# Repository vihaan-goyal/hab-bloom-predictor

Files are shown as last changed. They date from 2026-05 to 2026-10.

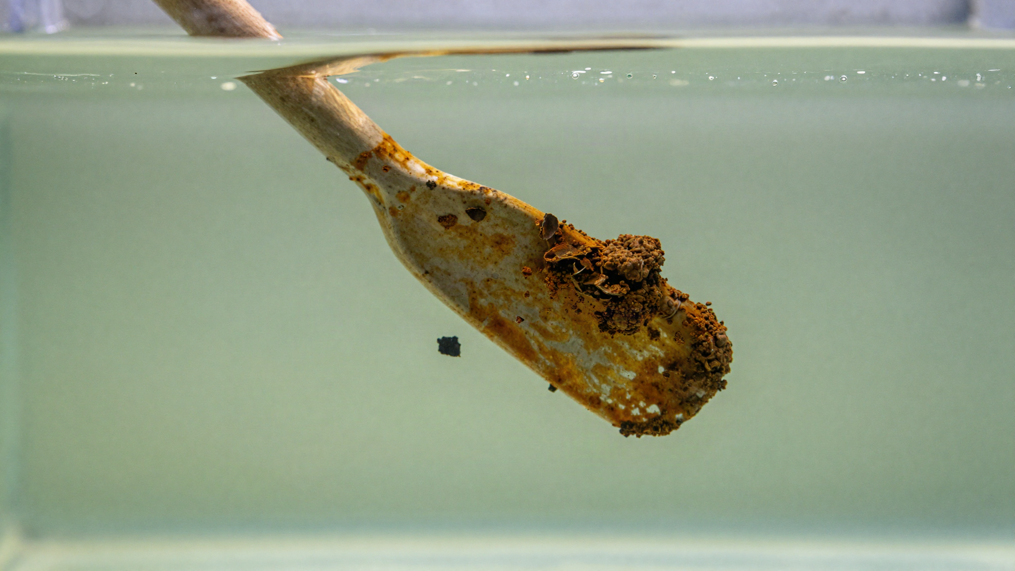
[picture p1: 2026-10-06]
figures/device_concept/shot1_flocs.png

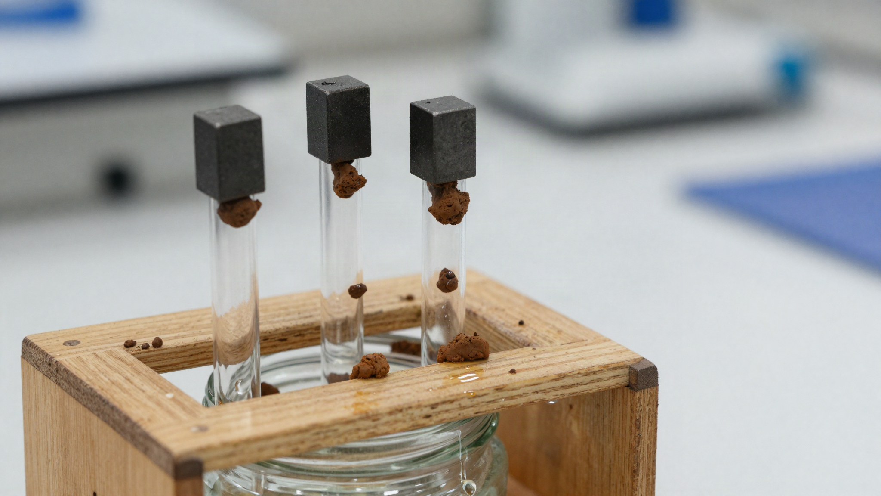
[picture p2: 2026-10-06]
figures/device_concept/shot3_release.png

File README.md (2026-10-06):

# HAB Bloom Predictor

**Predictability and its limits: a 21-day early warning system for chlorophyll exceedances in Long Island Sound**

Vihaan Goyal, Westhill High School, Stamford, Connecticut

---

**Label rebuilt (2026-09-23).** The Long Island Sound label used to come from DEEP's CTD fluorometer, which read 2.1-4.8x DEEP's own lab chlorophyll in 1994-1999, 1.8-3.2x in 2009-2013 and 0.8-1.05x from 2016 on. DEEP confirmed its lab and methods are unchanged for 30+ years, that the CTD switched from a SeaBird to a YSI EXO2 around 2009/2010, and recommended the lab data. The label and every chlorophyll feature were rebuilt on the lab scale (`Corrected_Chlorophyll`) under a pre-registration (S1, now the default), and all seven pre-registered predictions were right. Current numbers: `notes/S1_NUMBERS_SHEET.md`; rationale: `notes/LABEL_REBUILD_PREREG.md`.

## What this project shows

A regularized logistic regression forecasts chlorophyll-a exceedances (>10 ug/L within 21 days of a station visit) across Long Island Sound with useful ranking skill (pooled walk-forward AUC 0.693 after the 2026-09-28 audit; it beats a past-years calendar over 2016-2025, +0.077, p < 0.001, pre-registered, and ties it in 2023-25), but alert precision is capped near 0.12 regardless of model class, feature set, threshold, era, or spatial alerting policy. Thirteen pre-registered improvement attempts were rejected (sensor label; not re-run). The central finding is that this precision ceiling is mechanistic, not a modeling failure:

1. **Rarity.** Exceedances are rare in the test years (4.5% of station-days at the 21-day horizon), and rare events cap precision regardless of model. The low precision is mostly rarity, not only (the Sound also separates the classes less well, overlap 0.62 against 0.52 in Narragansett Bay). The old "2014 cliff" (sensor-label bloom share 0.42–0.59 in 2009–2013 → 0.03–0.11 from 2014) was mostly a CTD sensor scale change (SeaBird to YSI EXO2 around 2009/2010), confirmed by CT DEEP; the lab record has no 2014 step, but it does show a real, temporary low in 2012–2017. It is not a TMDL effect and not a DEEP lab change.
2. **Sampling.** The median gap between chlorophyll measurements is 21 days, equal to the forecast horizon. 48% of inter-sample gaps exceed the horizon, so many predicted events cannot even be verified.

Across eras and label definitions the system delivered a roughly constant 2.5 to 3.4x precision lift over the base rate on the sensor label (not re-run); after the 2026-09-28 audit the 21-day station-day lift is 1.63x at t* = 0.20. No intervention has moved that multiplier.

## The early warning system

**Leak fix (2026-09-28).** Four of the 35 features (`chl_climatology`, `chl_anomaly`, `tidal_gt_anom`,
`tidal_msl_anom`) were anomalies against climatologies averaged over the whole 1993-2025 record, so
test-period data leaked into training rows. They now use only data dated before each row
(`label_rebuild.py`, `add_tidal_features.py`; fix first found on the `worktree-climatology-fix`
branch, now archived as a tag). All numbers below are re-run on the leak-free features.

Operating point frozen by a pre-registered rule (highest threshold with out-of-sample 2020 to 2022 POD >= 0.8), evaluated once on out-of-sample 2023 to 2025 (walk-forward CV predictions, rebuilt label):

| Metric | Value | 95% CI (clustered bootstrap) |
|---|---|---|
| POD (recall) | 0.791 (34 of 43 events) | [0.636, 0.904] |
| FAR (1 - precision) | 0.885 | [0.835, 0.935] |
| Precision | 0.115 (~1.5x over 7.7% base rate) | [0.065, 0.165] |
| CSI | 0.122 (sensor label; not re-run) | [0.075, 0.169] |

Alert threshold t* = 0.20, from the pre-registered rule (highest threshold with out-of-sample 2020-22 POD >= 0.8), now the single constant `locked_pipeline.T_STAR_21` used by deploy and every analysis (decided 2026-09-28). On the original sensor label the table read POD 0.875, precision 0.125 over a 4.6% base rate, and selection-to-test transfer was near exact (POD 0.864 -> 0.875). At the 21 recurring-bloom stations (defined on pre-test data), detection is 91% at precision 0.137 (sensor label; not re-run). A station-gated alert policy was tested and rejected: false alarms arise at bloom-prone stations during non-bloom periods, so the ceiling is temporal, not spatial (sensor label; not re-run). A sustained-exceedance secondary label raises the lift to 3.4x but leaves precision near 0.10 (sensor label; not re-run).

The framing rationale: a missed bloom carries ecological and shellfish-industry costs, while a false alarm prompts a water sample at a station where, half the time, no sample would otherwise occur in the window.

## Locked pipeline

- Model: LogisticRegression, C=0.05, L2, balanced class weights, 35 features
- Label: any chlorophyll-a exceedance >10 ug/L within 21 days of a station visit
- Evaluation: rolling-origin cross-validation (train <= T-2, test = T), folds 2015 to 2025, station-year clustered bootstrap for all interval claims
- Canonical data file: `data/hab_features_tidal_S1.csv` (default; lab-consistent label), plus in-script merges of percent saturation and gust features. `HAB_FEATURES_CSV=data/hab_features_tidal.csv` reproduces the original sensor label.
- Dominant signal: chlorophyll history (~42% grouped feature importance; sensor label; not re-run)

Complexity does not help (sensor label; not re-run): XGBoost cost 33 points of precision against this baseline. Nutrient forward-fill, ERA5 wind, Kd490, neighbor bloom probability, station-month rates, and chlorophyll acceleration were all tested and rejected.

## Key ecological context

- The sharp 2014 step in the old sensor label was mostly a CTD sensor scale change (SeaBird to YSI EXO2 around 2009/2010), confirmed by CT DEEP on 2026-09-22/23; it is not a TMDL effect and not a DEEP lab change. The lab record has no 2014 step, but it does have a real, temporary low in 2012-2017 (lab exceedance share 0.03-0.07, against 0.10-0.23 before and 0.10-0.19 after)
- Biomass-bloom decoupling at western stations (A4, B3) after 2014, with near-zero NOx observations (sensor label; not re-run)
- Bloom frequency peaks February to March at 0 to 5 C, driven by cold-water diatoms, not summer cyanobacteria (sensor label; not re-run)
- Chlorophyll biomass (this project's target) skews west and tracks eutrophication; toxin-producing HAB species monitored by the state concentrate in eastern LIS. This system is a eutrophication early warning tool, not a direct toxin predictor.

## Repository structure

```
src/
  models/
    rolling_origin_cv.py            evaluation harness (canonical instrument)
    final_evaluation_threshold_sweep.py   single-split evaluation
    threshold_robustness.py         label-definition robustness (10 vs 12 ug/L)
    experiments/                    rejected improvement attempts (13)
  deploy/                           daily inference on the locked model;
                                    dashboard.html is stale (see DASHBOARD.md)
data/                               gitignored; see Data sources
figures/
paper/                              LaTeX (Overleaf)
```

Warning-system scripts (`scripts/warning/`): `scripts/warning/warning_operating_point.py` (threshold selection), `scripts/warning/warning_robustness.py` (CIs, extra years, per-station), `scripts/warning/warning_station_gate.py` (rejected gate experiment), `scripts/warning/grouped_station_report.py`.

## Data sources

| Source | Content | Access |
|---|---|---|
| CT DEEP / LISICOS via UConn ERDDAP | In-situ water quality, 1993 to 2025, ~monthly per station | public, merlin.dms.uconn.edu:8080 |
| UConn ERDDAP DEEP_Nutrient | Nutrient observations (NOx, DIP) | public |
| USGS stream gauges | Connecticut, Thames, Housatonic discharge | public |

The `data/` folder is not in git. Reproduce it from the public sources above; the raw water quality export is a single ERDDAP CSV query.

## Reproducing the headline numbers

```
conda activate base
python src/models/rolling_origin_cv.py --horizon 21      # pooled AUC 0.693 (S1, after the audit)
python scripts/warning/warning_operating_point.py --target-pod 0.8 --test-from-cv
python scripts/warning/warning_robustness.py --t-star 0.20
```

These use the S1 default input, `data/hab_features_tidal_S1.csv` (built by `python src/models/label_rebuild.py build`). Prefix with `HAB_FEATURES_CSV=data/hab_features_tidal.csv` to reproduce the original sensor label (pooled AUC 0.852 there).

## Status notes

- Horizon is standardized at 21 days throughout. An earlier single-split evaluation used a 28-day label; where its numbers appear in older notes they are superseded.
- `src/deploy/daily_inference.py` runs the locked pipeline (v2): it imports `locked_pipeline`, fits the LR walk-forward in-process, and loads no serialized model. The residual stale artifact is `src/deploy/dashboard.html`, whose sidebar still reads "Model: XGBoost / AUC 0.827" and which parses `aeration_score`/`do`/`temp`/`intervene` columns the current script no longer emits.
- Aeration intervention results are pending a rerun on corrected data and should not be quoted yet.

---

## Findings

Five results, each with the number that supports it. The negatives are the substance,
not the leftovers.

### 1. The alert beats "always alert", and nothing else

Until August 2026 this repo contained no trivial reference forecast, so "POD 0.875"
(the original sensor-label figure) had nothing to be measured against. `src/models/reference_baselines.py` adds four
(always-alert, station x month climatology, station x day-of-year climatology,
persistence) with a paired station-year clustered bootstrap of the lift difference.

| Level | base rate | model lift | clearly beats |
|---|---|---|---|
| Station-day (test, t*=0.20) | 0.077 | **1.63x** | always-alert only, +0.63 [+0.35, +0.92] |
| Basin-day (n=41, 9 events) | 9 of 41 | 1.75x | nothing; +0.76 [-1.00, +2.25] vs always-alert |

(Rebuilt, leak-free label, t*=0.35; before the 2026-09-28 leak fix 2.59x and basin 2.14x; was 2.63x on 956 rows / 48 events, and basin 1.37x on 12 events, on
the original sensor label.)

At station-day level the model is clearly better than no information. Persistence
scores a higher lift (3.26x) at a much lower POD (0.279 against the model's 0.791).
Climatology was not tested fairly on the rebuilt label (its validation-chosen threshold
degenerated to t=0, i.e. always-alert), so the original statement stands: not clearly
better than climatology. At basin level neither the model (1.75x) nor persistence clearly beats always-alert.

**Mechanism:** basin aggregation raises the base rate from 0.045 to 9 of 41 basin-days,
and lift = precision / base_rate. The aggregation that buys verification coverage spends
the model's clear advantage over always-alert. Report the station-day product, not the
basin one.

### 2. Searching 912 operating points finds noise

`src/models/basin_search.py` pre-registers a 912-cell grid (threshold x west-lon cut x
season gate x min-stations x aggregator), selects on validation only by a fixed rule,
and scores one configuration on test once. A permutation null re-runs the entire
search on shuffled labels.

- best real validation lift: **2.05x** (was 1.84x on the original sensor label)
- permutation null best-lift (200 shuffles): median **1.79x**, 95th percentile 2.86x
- the real result sits at the **70.5th percentile of noise**: inside the null

With this few validation events, any search over this space returns ~1.8-2x whether or
not the labels carry information. The selected configuration scores lift 1.56x on test;
that number is the output of selecting on noise and is not reported as an improvement. This is a direct quantitative demonstration of the failure
mode recorded in `notes/PRECISION_CEILING_INVESTIGATION.md` Finding 1.

### 3. The detector cannot see the HAB it is named for

`notes/BENCHMARKS.md` and Hattenrath-Lehmann & Gobler (2016) record that CTDEEP -- the
provider of this dataset -- reported *Cochlodinium* (rust tide) patches in Long Island
Sound in 2012 and 2016, plus an extensive bloom in Port Jefferson Harbor in 2016.

On the sensor label (not re-run), our Jul-Oct chlorophyll for 2016 is **0.6 sd below** the multi-year average (mean 4.21
vs 2012's 11.18), and across all 11,447 station-days exactly **one** reading reaches
the 100 ug/L rust-tide dense-patch level. Rust tide forms localised surface
aggregations that a station-day mean over multiple casts dilutes away.

Consequence for framing: chl-a > 10 ug/L is a **biomass** threshold, not a harm
threshold. Benign winter diatom blooms are counted; genuine HABs are missed. What this
model predicts is phytoplankton biomass exceedance. See `notes/LITERATURE_NOTES.md`.

### 4. Temperature is nearly uninformative here

Bloom rate below 15 C is **22.4%** versus **25.5%** at or above it (n=2,787
exceedances with paired temperature; sensor label; not re-run). A third of exceedances fall below the 15 C
threshold Reinl et al. (2023) use to define a cold-water bloom, and 20% below 5 C.
This cuts against the warming-drives-blooms framing that dominates the HAB
literature, and is consistent with the Feb-Mar cold-water diatom peak.

### 5. No point of no return exists

`src/models/point_of_no_return.py` tests, over 544 pre-onset observations (153 events),
whether a bloom ever becomes unavoidable. Two independent methods share **zero** rows. The
model-free test (50 matched historical analogues per state) peaks at **0.42**, median
0.02 (was 0.62 / 0.04 on the original sensor label). The model counterfactual's apparent
answer -- 42% of summer events locked in -- collapses to **0%** once temperature, salinity and tides are allowed
to move within their own observed station-season range, so it measures lever
restriction rather than inevitability.

### The rejected-attempts ledger, enumerated

This README previously said "thirteen pre-registered improvement attempts were
rejected" but named only seven and quantified one. The full ledger, with deltas where
they were logged (sources: `notes/PRECISION_OPTIMIZATION_LOG.md`,
`notes/PRECISION_PUSH_TRACKER.md`, `src/models/experiments/`):

| # | Attempt | Outcome |
|---|---|---|
| 1 | Nutrient forward-fill | **-10.4pp** precision (stale monthly samples) |
| 2 | NOAA ASOS wind (land-based) | **-4pp** |
| 3 | MODIS satellite CHL | **-7.8pp** (4 km too coarse) |
| 4 | ERA5 wind stress | **-6.3pp** (corr -0.003; wind is noise for LIS blooms) |
| 5 | Kd490 water clarity | **-2.2pp** (78.8% null in the merge) |
| 6 | UConn nutrients | **-4.9pp** (still monthly cadence) |
| 7 | River discharge lags | no signal, corr < 0.03 at every lag; screened out |
| 8 | Isotonic/Platt calibration | breaks the probability scale; val too small (~67 positives) |
| 9 | XGBoost | **-33pp** precision |
| 10 | Station-month bloom rate | rejected; delta not logged (`experiments/test_station_month_rate.py`) |
| 11 | Chlorophyll acceleration | rejected; delta not logged (`experiments/test_chl_acceleration.py`) |
| 12 | Neighbor bloom probability | rejected; delta not logged (`experiments/test_neighbor_bloom_prob.py`) |
| 13 | Station-gated alert policy | rejected; false alarms arise at bloom-prone stations in non-bloom periods, so the ceiling is temporal, not spatial |

Rejected since, under rolling-origin CV and this session's baselines (sensor label; not
re-run, except the basin search, re-run on the rebuilt label): selective
prediction / station abstention (CI [-0.024, +0.037] straddles zero); stratification
features (paired AUC -0.014 [-0.021, -0.007] — real physics, no marginal signal);
label refinement (raises raw precision 0.175 to 0.380 while lift *falls* 5.72 to 2.91 —
a base-rate illusion); the ensemble (+0.0038 AUC vs LR, CI [-0.0100, +0.0201]); and the
912-configuration basin operating-point search (70.5th percentile of its own permutation
null, i.e. inside it). The consistency of these failures across mechanism, model class, and alerting
policy is the precision-ceiling finding.

### Also worth knowing

- **Model class does not matter** (sensor label; not re-run). Ensemble vs locked LR on the same test split:
  +0.0038 AUC, 95% CI [-0.0100, +0.0201]. Every tree ensemble in
  `data/full_model_comparison_results.csv` scores clearly worse (VotingEnsemble 0.7918,
  StackedLR 0.7697) than LR (0.8139-0.8157).
- **A typical bloom onset carries one in-situ reading in the preceding month**
  (median 3 in 90 days; median inter-visit gap 21 days = the forecast horizon).
- **There is no spare data.** The raw ERDDAP export holds 106 real stations and 11,508
  station-days with usable chlorophyll; the model already uses 11,447 (~99.5%).

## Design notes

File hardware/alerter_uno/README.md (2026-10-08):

# Alerter on an Arduino Uno: build guide

The alerter is the loop's brain for one tank:
- each day it gets the forecast `p` and the tank's chlorophyll;
- it decides ON/OFF with the same rules as `src/sim/loop_controller.py`;
- it switches a relay (the treatment) and shows the state on LEDs and a buzzer.

The Uno has no Wi-Fi, so the laptop sends the daily values over USB. An ESP32 is only needed
later, if the box must run without a laptop.

**What gets measured, and how:**

| Measurement | Why | How | Auto / by hand | Stage |
|---|---|---|---|---|
| Chlorophyll | model input (required), OFF rule | DIY fluorometer | auto | 5 |
| Temperature | model input, safety | DS18B20 probe | auto | 3 |
| pH | safety (bubbling and percarbonate shift it) | analog pH probe | auto | 4 |
| Dissolved oxygen | model input (optional), safety < 4 mg/L | aquarium DO kit | by hand, daily | 6 |
| Salinity | model input (optional) | refractometer | by hand, every 2-3 days | 6 |
| Cell counts | the real endpoint; checks the fluorometer | microscope + Sedgewick-Rafter slide | by hand, every 1-2 days | 6 |
| Ammonia / nitrate / phosphate / H₂O₂ | method safety limits | test strips/kits | by hand, at each re-measure | 6 |
| Non-target survival | arm D harm check | *Artemia* 24-h survival | by hand | 6 |

**Build one stage at a time. Don't start the next stage until the current one passes its "done when" check.**
Dates fit `EXECUTION_PLAN.md`: build and calibrate by Oct 24, cultures Oct 15-31, warm-up Nov 10.

| Stage | What | Target | New cost |
|---|---|---|---|
| 0 | Parts check | Sep 27 | $0 |
| 1 | Logic + lights | Sep 27-28 | $0 (kit) |
| 2 | Relay + pump | by Oct 4 | ~$25 |
| 3 | Temperature | by Oct 4 | ~$8 |
| 4 | pH probe | Oct 5-11 | ~$30 |
| 5 | Fluorometer (chlorophyll) | Oct 5-18 | ~$20 |
| 6 | Hand-measurement kit | Oct 12-24 | ~$90 + borrowed microscope |
| 7 | Laptop link + logging | Oct 19-24 | $0 |
| 8 | Dry run on a real tank | Oct 26 - Nov 9 | $0 |
| 9 | Dosing module (inline dilution, peroxide) | Oct 12-24 | ~$70 |

**Progress:** stages 1 and 2 passed on 2026-09-26: Test A, lights, buzzer, and the bare relay
clicking on D10 (LED as the pretend pump; the real pump isn't bought yet).
On 2026-09-30 the new Uno (COM5) passed Tests A, B and C by hand, every line matching, and the bare
relay clicked on D10 with `hardware/relay_click_test/relay_click_test.ino` (toggles D10 every second).
On 2026-10-05 the Adafruit TSL2591 (STEMMA QT cable, no soldering) read on the new Uno with `USE_TSL2591 1`;
the pH board reads (zero point ~3.6 V in tap water, buffers not yet bought, so not calibrated).
On 2026-10-07 the DS18B20 probe (red/yellow/blue leads taped to jumpers, 4.7 kΩ pull-up, 12-bit) read
correctly on D3 (user report: stage 3 passed).

## Shopping list (what to order now)

Already on hand: Uno, breadboard, M-M wires, blue/green/white LEDs, 220/330/10k Ω resistors,
PN2222A transistors, passive buzzer, bare 5 V relay, 1N4007 diode.

| # | Item | For | Approx. |
|---|---|---|---|
| 1 | Male-to-female jumper wires ([ELEGOO 120-pc M-F/M-M/F-F](https://www.amazon.com/dp/B01EV70C78)) | relay pins, sensor boards | $6 |
| 2 | 12 V diaphragm air pump ([search: 12 V diaphragm air pump](https://www.amazon.com/s?k=12v+dc+diaphragm+air+pump+aquarium); the listing found first is gone) + 12 V 2 A adapter with barrel-jack screw terminals ([bundle](https://www.amazon.com/dp/B08GX5Z4MR)) + air tubing and an air stone | stage 2 (the real pump) | $20 |
| 3 | DS18B20 **waterproof** probe ([5-pack with 4.7 kΩ resistors](https://www.amazon.com/dp/B0C8J77NJR)) | stage 3 | $10 |
| 4 | pH module + BNC probe ([PH-4502C type](https://www.amazon.com/dp/B07KDPQGYD)) + buffer powders 4.00/6.86/9.18 ([VIVOSUN 18-pack](https://www.amazon.com/dp/B0D4L8Y7BT)) | stage 4 | $35 |
| 5 | [Adafruit TSL2591](https://www.amazon.com/dp/B00XW2OFWW) + [LEE 106 Primary Red gel](https://www.amazon.com/dp/B003DIGLV8) + cuvettes with **4 clear sides** ([Globe 4.5 mL, 100](https://www.amazon.com/dp/B08N5B5PL8)) + [470 nm blue LEDs](https://www.amazon.com/dp/B091SLR9SB) | stage 5 | $40 |
| | **Total** | | **~$110** |

Links found 2026-09-26; check the price, the rating and that it still matches before buying. The
cuvettes must have 4 clear sides, because the sensor looks in at 90° to the LED. Calibrate the pH probe
with the 6.86 and 9.18 buffers (they bracket seawater's ~8).

Stage 6 (hand kits: DO kit, refractometer, counting slide, test strips, ~$90) can wait until mid-October;
it's listed in stage 6 below and in `notes/mitigation/MATERIALS_LIST.md`.

---

## Stage 0: parts check

Go through the kit against the stage 1 list. Write down what's missing, and order stages 2-5 parts together (one shipping wait).

**Done when:** you have everything for stage 1 on the desk, and the stage 2-5 order is placed.

## Stage 1: logic + lights (kit parts only, ~1 hour)

**Parts** (on hand): Uno, breadboard, green, blue and white LEDs, 220/330 Ω resistors, passive buzzer, NPN transistor + 330 Ω–1 kΩ, M-M jumper wires.

**Visual wiring: [circuito.io design](https://www.circuito.io/app?components=512,9591,9594,11021,11050,11372,956215)**
(snapshot `wiring_circuito.jpg`). Build it exactly as shown, with two colour swaps:
- circuito's **yellow** LED = your **white** LED (warning);
- no relay in the picture: D10 stays empty until the relay goes there in stage 2; the blue LED already shows when the relay would be ON.

The sketch uses circuito's pins:

| Uno pin | Goes to |
|---|---|
| D6 | green LED → 330 Ω → GND: **idle** |
| D5 | blue LED → 100 Ω (220 Ω also fine) → GND: **treatment ON** |
| D9 | white LED (circuito's yellow) → 220 Ω → GND: **warning** |
| D10 | empty in stage 1; stage 2: the relay transistor |
| D2 | 330 Ω → NPN transistor base; buzzer between 5V and the collector; emitter → GND |
| D3 | DS18B20 yellow wire, 4.7 kΩ to 5V (stage 3) |
| 5V / GND | breadboard rails |

`schematic.png` (drawn by `draw_schematic.py`) is the same circuit as a circuit diagram, plus the
bare-relay driver that circuito can't draw.

The sketch drives a **passive** buzzer (it plays a 2 kHz tone). Change `BUZZ_HZ` for a different pitch.

⚠ **Full-size breadboards split their power rails in the middle** (look for a gap in the red/blue
lines). Jumper the top + to the bottom + and the top − to the bottom −, or parts in the bottom half
get no power. This silenced the buzzer on 2026-09-27: it was in the bottom half, powered from a dead rail.
A buzzer wired straight from D2 to GND also works, just more quietly.

**Flash it:**
1. Open `alerter_uno.ino` in the Arduino IDE.
2. Select Board → Arduino Uno and the COM port, then click Upload.
3. Open the Serial Monitor at **115200** baud with **"Newline"**.

**Test A**: paste one line at a time (X = 3, C_ok = 5):

```
1 0.2 3      -> idle            (green)
2 0.6 4      -> START           (3 beeps, blue, next_check=5)
3 0.7 6      -> ON
4 0.7 8      -> ON
5 0.5 9      -> ON next_check=8 (p not below T_off 0.40: keep going)
8 0.3 4      -> OFF             (1 long beep, green)
9 0.3 3      -> idle
```

**Test B (MAX_ON = 12 days)**: send `reset`, then `1 0.6 4`, then days 2-14 as `<day> 0.9 20`.
- Day 13 prints `STOP_MAX_ON`.
- Day 14 restarts (episodes=2), because `p` is still high.

The Python controller gives the same states on both tests (checked 2026-09-26).

**Test C (handover + floor, added 2026-09-28)**: send `reset`, `x 3`, `cok 3`, `mode H`, `warm 2`,
`floor 0.8`, then one line at a time:

```
1 0.1 2.0    -> idle
2 0.1 2.2    -> idle
3 0.1 4.6    -> idle            (rule fires: rose 2 days and > 2 x warm; forecast still low)
4 0.2 5.1    -> idle
5 0.2 6.0    -> START           (handover: rule fired 2 days ago, forecast never did)
6 0.3 6.5    -> ON
8 0.3 7.0    -> ON              (day 7 skipped: fine)
9 0.3 1.5    -> ON              (1st reading below the floor 0.8 x 2 = 1.6)
10 0.3 1.4   -> OFF_FLOOR       (2nd in a row: H4 floor OFF)
11 0.3 1.3   -> idle
12 0.6 5.0   -> START           (forecast)
```

`alerter_link.py --replay <file> --sim --mode H --warm 2 --floor 0.8 --x 3 --cok 3` prints the same
states (Python reference, 2026-09-28). Run it on the board too: 0 mismatches is the pass mark.

**Other commands:**
- `status`
- `x 2`, `cok 4.5`
- `mode F` (forecast only), `mode R` + `warm 1.8` (rule trigger: chl rose on 2 calendar days AND
  > 2 × warm-up mean), `mode H` + `warm 1.8` (forecast, with the 2-day handover to the rule: arm B)
- `floor 0.8` (H4: 2 readings in a row below 0.8 × warm while ON → `OFF_FLOOR`; `floor 0` for the
  false-alarm arm D), `maxon 3` (MAX_ON in **days since START**; 0 = 4 × X; peroxide 3 with `x 1`)
- `pulse <s>` (added 2026-10-02, peroxide dosing pump): while ON, the relay runs for `<s>` seconds at
  START and at each check day that continues the episode, then switches off; the state still prints
  `ON`, and the day line ends with `pulse=<s>s`. `pulse 0` (default) holds the relay for the whole
  episode (air pump), so Tests A-C are unchanged.
- `skip`: the next pulse is skipped (the day line shows `pulse=skipped`); send it when the low-range
  kit reads an H₂O₂ residual above 0.5 mg/L.
- **Peroxide setup:** `x 1`, `maxon 3`, `pulse <s>`, where `<s>` = seconds the calibrated pump needs to
  deliver the pulse volume (0.265 mL of 3% per 10 L for 0.8 mg/L; from the weigh-calibration in
  mL/s). Because MAX_ON counts days since START, this gives at most 3 pulses (START day and the next
  two check days) and `STOP_MAX_ON` on day 4. The 2.8 mg/L residual stop and the pH > 9.0 stop are
  **not** automatic in the firmware: send `stop` by hand, or use `alerter_link.py --stop "..."` /
  `--ph-max 9.0`.
- `temp 10 17` (temperature warning window; default 10-17 °C for the planned 12-15 °C run)
- `stop` for a safety stop, e.g. when the DO kit reads < 4 mg/L. With the laptop link, use
  `--today ... --stop "DO 3.6 mg/L"` instead, so the stop is logged and replayed after a reset.

**Done when:** Tests A, B and C print exactly the lines above, and the LEDs and buzzer match.

## Stage 2: relay + pump (~$25)

**Parts:**
- 1- or 2-channel 5 V opto-isolated relay module;
- a 12 V aquarium air pump (or peristaltic pump) + 12 V adapter;
- a DC barrel jack or screw-terminal adapter.

**Wiring:**
- Relay VCC→5V, GND→GND, IN→D10.
- The pump's 12 V + wire goes through the relay's **COM → NO** contacts; the − wire goes straight back to the adapter.
- The Uno and the 12 V pump do **not** share power.
- Most relay modules are **active-low**: with a module, set `RELAY_ACTIVE_LOW = true`. If the relay clicks ON while the sketch says idle, flip it.

**Bare 5-pin relay instead of a module** (the kit's blue SRD-05VDC-SL-C). Breadboard picture:
`relay_breadboard.png` (drawn by `draw_relay_breadboard.py`, since circuito.io can't draw this part).
- The coil needs ~70-90 mA, more than an Uno pin can give, so drive it with the NPN transistor:
  - D10 → 330 Ω (or 1 kΩ) → transistor **base**;
  - **emitter** → GND;
  - **collector** → one coil pin; the other coil pin → 5V.
- Put a **1N4007 diode across the coil**, with the striped end (cathode) on the 5V side. It absorbs the voltage spike when the coil turns off; without it the transistor or Uno can die.
- Pins: the top of the relay shows the pinout. With the relay off, **COM** is connected to **NC** (a multimeter beeps). The pump goes on **COM → NO**.
- `RELAY_ACTIVE_LOW = false` (the sketch default): a HIGH on D10 turns the transistor, and so the relay, on.
- The legs sit across the breadboard's centre gap. If they don't fit, solder short wires on.

⚠ **Never put 120 V mains on the breadboard or a bare relay.** A mains-powered pump goes on a
**smart plug** or an enclosed relay box ("IoT Power Relay") on a **GFCI** outlet, with the
sponsor's OK.

**Done when:** rerunning Test A makes the pump run from day 2 to day 8, and stop otherwise.

## Stage 3: temperature (~$8)

**Parts:** DS18B20 **waterproof** probe, 4.7 kΩ resistor (or two 10 kΩ in parallel).

**Wiring:**
- red→5V, black→GND, yellow→D3;
- the resistor goes between D3 and 5V.

**Code:**
- Arduino IDE → Library Manager → install `OneWire` and `DallasTemperature`.
- Set `USE_DS18B20 1` at the top of `alerter_uno.ino` (the code is already written and compile-checked).
- It reads every 10 s and alarms outside the window (default 10-17 °C, set with `temp <lo> <hi>`;
  white LED, fast beeps). `read` prints all sensors; `status` shows the temperature.

**Done when:**
- the probe agrees with a kitchen thermometer within 0.5 °C in a glass of water;
- ice water triggers the alarm, and room-temperature water clears it.

## Stage 4: pH probe (~$30)

**Parts:**
- analog pH probe kit with a BNC probe and the blue PH-4502C board (or DFRobot Gravity pH);
- pH 4.00, 6.86 and 9.18 buffer powder packets (calibrate with 6.86 and 9.18);
- distilled water for rinsing.

**Wiring:** board V+→5V, G→GND, Po→**A2** (A4/A5 are the TSL2591's SDA/SCL). Needs a working analog
header: the old Uno's broke off, so use the new board or a re-soldered header.

**Code** (written, compile-checked): set `USE_PH 1`. Then:
1. Probe in **pH 6.86** buffer, wait 1 min, type `cal686`.
2. Rinse, probe in **pH 9.18** buffer, wait 1 min, type `cal918`.
3. `read` now shows `ph=` (and the raw `ph_v=` volts). Calibration is stored in the Uno's EEPROM and
   survives unplugging; `cal` shows it, `calclear` erases it.
- `alerter_link.py --today` sends a **safety stop** if pH is outside 7.6-8.6 (change with
  `--ph-min/--ph-max`; peroxide runs use `--ph-max 9.0`). A safety stop ends a running treatment; it
  doesn't block a new start that day (same as the Python controller's `force_off`).

**Tips:**
- Store the probe tip wet (its cap with storage solution), never dry.
- The probe can read noisily when the air pump shares the water. Compare readings with the pump on and off.

**Done when:**
- the 6.86 and 9.18 buffers read within ±0.1 after calibration;
- seawater reads ~7.9-8.3 and agrees with a test strip.

## Stage 5: the fluorometer, chlorophyll (~$20, the hard part)

A blue LED makes chlorophyll glow red. A light sensor behind a red filter measures that glow.

**Autonomous accuracy (added 2026-10-02; the device must keep itself honest between service visits).**
Only the first item is built. The reference target, wiper, drift alarm and automatic rescaling are
**planned, not yet built**; the target and wiper need the servo (D11, `USE_SERVO`), which is
otherwise unused since 2026-10-01.
- **Dark reading every measurement:** LED off, LED on, subtract. Already in the code.
- **Reference target (planned):** once a day the servo swings a small piece of fluorescent plastic (or a sealed
  dye vial) in front of the sensor. Its reading should never change, so the device rescales `chlk`
  automatically when the LED or sensor drifts.
- **Wiper (planned):** the servo sweeps a soft rubber blade across the window before each reading, as RIDEM's
  sondes do.
- **Drift alarm (planned):** the device tracks its clear-water floor (lowest readings). If the floor rises for 3 or
  more days, it flags "needs cleaning".
- **Initial calibration** (blank + multiplier) is done once at setup against a reference: lab chlorophyll,
  cell counts, or a sonde. Service visits re-check it with 1-2 reference samples.
- **Side-by-side with a sonde (the main validation; plan §12 in `notes/mitigation/EXECUTION_PLAN.md`):**
  - deploy within about 1 m of a RIDEM or Narragansett Bay NERR sonde for 2-4 weeks;
  - fit `blank` and `chlk` as one linear fit of device counts against sonde µg/L (the same kind of
    correction DEEP applies to its own CTD);
  - report r, bias and drift. The target is ±20% of the sonde.

**Parts:**
- TSL2591 light-sensor breakout (Adafruit, works on 5 V);
- 470 nm blue LEDs + 220 Ω;
- red gel filter sheet (Roscolux/Lee "primary red", or a red theatre gel sample pack);
- square plastic cuvettes (4.5 mL);
- a small black box (3D print, or black foam board and tape).

**Layout:** the LED shines into the cuvette from one side. The sensor, behind the red filter, looks
in from 90° so it sees the glow, not the LED. Keep everything light-tight.

**Wiring:** TSL2591 VIN→5V, GND→GND, SDA→**SDA**, SCL→**SCL** (the two pins beside AREF, above D13;
same signals as A4/A5); blue LED on **D7** → 220 Ω → GND. STEMMA QT cable: red 5V, black GND,
blue SDA, yellow SCL.

**Code** (written, compile-checked): Library Manager → install **Adafruit TSL2591 Library** and
**Adafruit Unified Sensor**; set `USE_TSL2591 1`.
- `read` turns the blue LED off and on, takes 3 readings each (200 ms), and prints the difference as
  `fl=`, so room light cancels out. Too bright ("SATURATED") → `gain l`; too faint → `gain h` or `gain x`.
  The gain is saved with the calibration (EEPROM); changing it tells you to redo `blank` and `chlk`,
  because both are only valid at the gain they were measured at.
- **Zero:** cuvette of plain seawater in the box → `blank`.
- **Scale:** `chlk` is **µg/L of chlorophyll per signal count**. After the dilution series (below), fit
  reference chlorophyll in µg/L (acetone extraction, or a borrowed calibrated fluorometer) against
  `fl`, and type `chlk <slope>`. C_ok and the floor are then in µg/L. (If no µg/L reference exists,
  fit cells/mL instead and give C_ok and `warm` in cells/mL too; never mix the two units.)
  Then `read` prints `chl=` in µg/L, and `alerter_link.py --today --p 0.6` uses it automatically
  (leave out `--chl`).

**Calibration** (once cultures arrive):
1. Make a dilution series of the culture (100%, 50%, 25%, 12.5%, 6%, 0% in seawater).
2. Read each one 3 times.
3. Cell-count each one.
4. Fit reading vs cells (and µg/L if extracted chlorophyll is possible).

**Done when:**
- the blank (seawater only) reading is stable within ±5% over 10 minutes;
- the dilution series is a straight line (R² > 0.95).

## Stage 6: hand-measurement kit (~$90 + borrowed microscope)

| Item | Approx. |
|---|---|
| Aquarium DO test kit (saltwater) | $15 |
| Salinity refractometer (ATC) | $20 |
| Sedgewick-Rafter counting slide + transfer pipettes | $25 |
| Ammonia kit, nitrate/phosphate strips, H₂O₂ strips | $30 |
| Microscope (borrow from school) | $0 |

**Practice** on a culture flask for 3 days before any experiment. Do each measurement the way
you will in the real run, and fill in `src/lab/lab_data_template.csv`.

**Done when:**
- 3 days of practice data in the template;
- two counts of the same sample agree within 20%.

## Stage 7: laptop link + logging

**Script: `alerter_link.py`** (written 2026-09-27; needs `pip install pyserial`; close the Arduino IDE
Serial Monitor first, since only one program can use the port).

```
python hardware/alerter_uno/alerter_link.py --ports                  # find the Uno's COM port
python hardware/alerter_uno/alerter_link.py --demo                   # Test A, automatically
python hardware/alerter_uno/alerter_link.py --replay narragansett:F7 --days 400   # real history
python hardware/alerter_uno/alerter_link.py --today --p 0.62 --chl 7.4 --start 2026-11-10
```

- Every Uno reply is checked against the Python controller; any `MISMATCH` is printed and logged.
- Log: `hardware/alerter_uno/logs/alerter_log.csv` (not committed).
- **Uno resets:** opening the USB port restarts an Uno and wipes its ON/OFF state. `--today` replays the
  earlier days from the log with the buzzer muted (`mute 1`), then sends today's line.
- Add `--sim` to any command to try it with no board (a stand-in Uno built from the Python controller).
- **Checked on the real Uno (2026-09-27):** `--demo` (lights, beeps and relay clicks right), and all 3,287 days of
  Narragansett station F7 in 50 s: 115 ON days, 10 episodes (6 ended at MAX_ON, as expected on untreated
  water), **0 mismatches** with the Python controller, including days with missing `p` or chlorophyll.
- Later: read chlorophyll, temperature and pH from the Uno's sensors, and get `p` from the model automatically.

- **Loop settings (2026-09-28):** `--mode H` (default; arm B), `--warm <mean>`, `--floor 0.8` (0 for arm D),
  `--maxon 0|3`, `--temp-lo 10 --temp-hi 17`, `--stop "reason"` (logged manual safety stop). Values
  are sent with 6 significant figures and the Python reference uses the sent value, so a reading right
  at a threshold cannot disagree.

**Done when:** a 48-hour test logs with no gaps, and unplugging the USB and reconnecting it recovers cleanly.

## Stage 8: dry run on a real tank (Oct 26 - Nov 9)

Run one tank of plain seawater + culture at low nutrients for 2 weeks, exactly as the warm-up
will run:
- sensors logging;
- daily hand measurements;
- the loop active on the rule trigger (`--mode R --warm <warm-up mean>`).

**Done when:**
- 14 days with no missing daily rows;
- the fluorometer tracks the cell counts;
- nothing overheats, leaks or drifts.

Then the real 21-day warm-up starts on Nov 10.

## Stage 9: dosing module, inline dilution (added 2026-10-03; ~$70)

The peroxide is never squirted straight into the water. A circulation pump draws water in, the dosing
pump meters peroxide into that stream, a mixing hose blends it, and the mix leaves beside the air
stone. In the field the reservoir holds **7% H₂O₂**; on the bench it holds the **0.1% working
dilution** (`PROCEDURES.md` P6), because 0.8 mg/L in 10 L is only 0.11 mL of 7%, too little to meter.

```
water → intake (2-5 mm screen) → circulation pump (12 V) → mixing tee → 1 m mixing hose → outlet beside the air stone
H₂O₂ jug (opaque HDPE, float switch) → peristaltic dosing pump → check valve ──────┘ (into the tee)
```

**Parts:** 2-channel 5 V relay module; 12 V circulation pump (bench: small aquarium pump; field:
10-20 L/min); the peristaltic dosing pump (stage 2); intake screen; check valve; tee + 1 m hose (or an
inline static mixer); flow switch; float switch; opaque HDPE jug; peroxide-compatible tubing
(silicone in the pump head, PE/PVC elsewhere). Details in `notes/mitigation/MATERIALS_LIST.md`.

**Wiring:**
- Relay channel 1 IN → **D10** (dosing pump, as before); channel 2 IN → **D12** (circulation pump).
  Each pump's 12 V + goes through its channel's COM → NO. A 2-channel module is usually active-low:
  set `RELAY_ACTIVE_LOW = true` (it applies to both channels).
- Flow switch between **D8** and GND (closed = flow). Float switch between **D4** and GND (closed =
  reservoir low). Both use the Uno's internal pull-ups, so no resistors.
- Set `USE_DOSER 1` at the top of `alerter_uno.ino` (with it at 0 the sketch behaves exactly as before).

**What the firmware does** (with `pulse <s>` > 0): each pulse runs **PRIME** (circulation only, 5 s) →
**DOSE** (circulation + dosing pump, `pulse` seconds) → **FLUSH** (circulation only, `flush` seconds,
default 90) → idle, printing `DOSER prime`, `DOSER dose`, `DOSER flush`, `DOSER idle`.
- **No-flow interlock:** no flow at the end of PRIME, or flow lost for more than 0.5 s during DOSE →
  both pumps stop, `DOSE_ABORT no_flow`, 3 beeps, white LED. Later pulses print `pulse=aborted` and
  do not run until the intake is fixed and `pulse <s>` is sent again (or `reset`).
- **Reservoir low:** the float is checked every 10 s; on LOW it prints `REFILL` once and lights the
  white LED. Dosing still runs (the jug holds a margin below the float).
- `status` adds `flush=`, `circ=`, `flow=`, `level=` (and `dose=FAULT` after an abort).

**Pump calibration:**
1. Fill the jug with the solution it will dose (bench: 0.1%). Prime the dosing pump's tube.
2. Run the dosing pump for **30 s** into a 10 or 25 mL graduated cylinder; repeat 3 times; average.
3. Rate (mL/s) = volume ÷ 30. `pulse` seconds = pulse volume ÷ rate, rounded to whole seconds.
   Bench example: 50 mL in 30 s = 1.67 mL/s; 8 mL of 0.1% per 10 L → `pulse 5`. If the rounding error
   is over 5%, use a slower pump or a weaker working dilution.
4. Record the rate in the design log; re-check it at every service visit (tubing wears).

**Dry bench test** (LEDs in place of the pumps, jumper wires as the switches):
1. `x 1`, `maxon 3`, `pulse 3`, flow jumper D8 → GND, then `2 0.6 4` → `START ... pulse=3s`, then
   `DOSER prime`, `DOSER dose` (3 s), `DOSER flush` (90 s), `DOSER idle`, with the LEDs in that order.
2. Remove the flow jumper and send the next check day (`3 0.6 4`) → `DOSE_ABORT no_flow` after 5 s, 3
   beeps, white LED. The next check day prints `pulse=aborted`; `pulse 3` re-arms it.
3. Ground D4 → `REFILL` within 10 s, white LED on.

**Water mixing test** (10 L tank of seawater, 0.1% in the jug, pump calibrated): run one pulse, then
measure H₂O₂ with the low-range kit at the **outlet** and the **far corner** at 1, 5 and 15 min.

**Done when:**
- the dry test prints the three sequences above;
- in the water test the far corner reads **0.8 ± 0.2 mg/L by 15 min** and the outlet reads **< 5 mg/L
  at 5 min** (no hot spot).

## Optional: servo (D11; planned for the fluorometer wiper and reference target)

Since 2026-10-01 no treatment needs a servo (aeration and peroxide are switched by the relay). It is
kept for the planned wiper and reference target (stage 5, "Autonomous accuracy"); that code is not
written yet, and today `USE_SERVO` only moves the servo with the treatment state.
- **Wiring:** servo signal (orange/yellow) → **D11**; servo red → an external 5-6 V supply (not the
  Uno's 5 V pin: a stalled servo browns out the Uno); servo brown/black → GND, **shared with the Uno's GND**.
- **Code:** set `USE_SERVO 1` (Servo library, built in). The servo goes to the ON angle while
  treatment is ON and back to the OFF angle otherwise. `servo 90 0` sets the ON / OFF angles.
- The Servo library takes Timer1, so pins 9 and 10 lose PWM. That is fine here: the white LED (D9) and
  the relay (D10) only use on/off.
- **pH note:** `readPhVolts` assumes a 5.000 V reference. USB gives 4.7-5.1 V, so recalibrate the pH
  probe (`cal686`, `cal918`) whenever the power source changes, and run from the same supply.

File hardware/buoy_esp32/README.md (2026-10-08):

# Bloom-forecast buoy on an ESP32

This sketch runs the Narragansett Bay bloom forecast on an ESP32 chip, with no computer attached.
The forecast is the fork's release model v2: 300 small decision trees that give
**P(daily chlorophyll > 10 µg/L within the next 7 days)**. The board raises an alert when p ≥ 0.45.

The board builds the model's 23 inputs from its own daily history in the same way the training code
did. These inputs are chlorophyll, its last 4 days, its rolling means, trend, anomaly and
climatology, plus temperature, salinity, oxygen and month. The board then scores them.

**A bare ESP32 with no sensors works out of the box.** In that case it runs in DEMO mode: you type
(or stream) one line per day, and it prints the forecast.

## Files

| File | What it is |
|---|---|
| `buoy_esp32.ino` | The sketch: commands, alert outputs, sensors (each off until enabled), NVS storage |
| `bloom_model.h` | The model as C arrays. **Generated in the fork**; do not edit (see "Regenerating") |
| `features.h` | Builds the 23 features from the daily history, matching training rule for rule |
| `pss78.h` | Converts conductivity and temperature to salinity (PSS-78) |
| `selftest.h` | The boot self-test |
| `test_vectors.h` | Real data rows plus Python's answers for the self-test. Generated by `make_test_vectors.py` |
| `replay_demo.py` | Streams a real station's days to the board and compares the board with Python |

## 1. Upload (about 5 minutes)

1. Install the **Arduino IDE 2**. Go to **File → Preferences → Additional boards manager URLs** and
   paste `https://espressif.github.io/arduino-esp32/package_esp32_index.json`.
2. Open **Tools → Board → Boards Manager**, search for **esp32** and install
   **"esp32 by Espressif Systems"**.
3. Open `hardware/buoy_esp32/buoy_esp32.ino`. The other files in the folder open as tabs; leave them.
4. Select **Tools → Board → esp32 → ESP32 Dev Module**.
5. Plug in the board and pick its port under **Tools → Port** (COM3, COM5, …).
   - If no port appears, install the USB driver for the chip on your board: CP210x or CH340.
6. Click **Upload** (→).
   - If the upload stops at `Connecting....`, hold the board's **BOOT** button until the
     percentages start.
7. Open **Tools → Serial Monitor**. Set it to **115200 baud** and **Newline**.
   - Press the board's **EN** (reset) button to watch the boot.

## 2. The self-test (runs at every boot)

```
SELFTEST begin: model 300 trees, 23 features, threshold 0.45, horizon 7 d
  [names]    feature order matches bloom_model.h: PASS
  [model]    row                       C     Python       diff  decision
  [model]    B3 2013-07-04      0.998575   0.998575  +2.90e-08  ALERT/ALERT PASS
  ...  (8 real station-days: 2 clear alerts, 2 near the 0.45 line, 2 clear no-alerts, 2 with missing inputs)
  [features] 8 days x 23 features vs fork columns: max |diff| 1.91e-06  PASS
  [pss78]    S(R=1,15C,0)=35.0000 (35)  S(R=1.888091,40C,10000dbar)=40.0000 (40)  PASS
SELFTEST PASS (0 failures)
READY mode=DEMO. ...
```

The self-test makes four checks:

- **model:** the chip's probability minus Python's must be smaller than 0.002, and both must make
  the same ALERT/idle decision.
- **features:** 29 real days from station B3 go through the chip's feature code. The last 8 days
  must equal the training table's columns.
- **pss78:** the salinity formula must reproduce the two official UNESCO check values.
- **names:** the feature order in `features.h` must match the model's.

The onboard blue LED shows the result: **3 slow blinks = pass, 10 fast blinks = FAIL**.

Type `selftest` to run it again.

## 3. Demo: type days, get forecasts

Each line is one day of **daily means**:

```
day <yyyy-mm-dd> <chl ug/L> <temp C> <salinity PSU> <DO mg/L> [chl climatology]
```

- Write `nan` for a missing value. The model then uses the training median for it, as it did in
  training.
- The optional 6th number is that day's chlorophyll climatology (see Limitations).

Copy and paste these 10 real days from RIDEM station B7, August 2020, all at once:

```
reset
day 2020-08-08 7.11 24.34 30.62 7.09
day 2020-08-09 6.66 24.50 30.58 7.17
day 2020-08-10 5.88 24.71 30.50 6.94
day 2020-08-11 5.82 25.03 30.46 7.01
day 2020-08-12 6.97 25.47 30.75 7.12
day 2020-08-13 10.32 25.70 30.59 7.41
day 2020-08-14 10.93 25.74 30.21 7.62
day 2020-08-15 10.36 24.76 29.95 6.81
day 2020-08-16 14.80 24.07 29.87 6.50
day 2020-08-17 12.66 23.36 29.37 7.30
```

The board prints a feature line (`F ...`) and a forecast line for each day. You should see these
forecast lines (Python gives the same numbers):

```
P 2020-08-08 p=0.364382 idle n=1
P 2020-08-09 p=0.385229 idle n=2
P 2020-08-10 p=0.380588 idle n=3
P 2020-08-11 p=0.370153 idle n=4
P 2020-08-12 p=0.406912 idle n=5
P 2020-08-13 p=0.759084 ALERT n=6     <- onboard LED and relay pin (GPIO 26) turn ON
P 2020-08-14 p=0.815180 ALERT n=7
P 2020-08-15 p=0.779669 ALERT n=8
P 2020-08-16 p=0.966618 ALERT n=9
P 2020-08-17 p=0.933513 ALERT n=10
```

Other commands:

| Command | Does |
|---|---|
| `status` | Mode, self-test result, days in the history, last p, ALERT/idle, climatology table |
| `hist` | Lists the stored days (at most the last 30) |
| `reset` | Clears the daily history. Calibration and climatology are kept |
| `vec <23 numbers>` | Scores a raw feature vector, in the order of `BLOOM_FEATURES` in `bloom_model.h` |
| `clim <month> <value>` | Stores the site's chlorophyll climatology for that month (`nan` clears it). `clim` alone shows the table; `climclear` erases it |
| `selftest`, `help` | Run the self-test again; list the commands |

Some details of how days are handled:

- **Repeated date:** sending the same date again replaces that day and rescores it.
- **Older date:** an older date is refused. Send `reset` first.
- **Skipped dates:** the board accepts them. "Yesterday" means the previous *row*, exactly as in
  training.

## 4. Replay a real station from the PC

`replay_demo.py` sends a station's real daily rows from the fork's
`data/narragansett_daily_features.csv` to the board. For each day it prints the board's p next to
Python's p. Python's p is computed from the same history by the same feature rules and the same
model. Any mismatch is flagged.

```bash
# close the Serial Monitor first (only one program can use the port)
~/anaconda3/python.exe hardware/buoy_esp32/replay_demo.py --port COM5 --station B3 --start 2023-07-01 --days 60
# no board: the Python path alone, compared with the fork's precomputed training columns
~/anaconda3/python.exe hardware/buoy_esp32/replay_demo.py --sim --station B3
```

Options:

- `--start` streams the 21 days before it as warm-up.
- `--clim none` leaves the climatology out, as a brand-new buoy would have to.
- The script needs `pyserial` for a board: `pip install pyserial`.

Result on 2026-10-05: `--sim` reproduces the fork's 23 training columns exactly for all 18
stations: 42,315 days, largest difference 9e-14, zero alert disagreements.

## 5. Sensors (later)

Turn a sensor on by setting its flag to 1 near the top of `buoy_esp32.ino`. Any flag at 1 switches
the board to **SENSOR mode**. In that mode the board:

- samples every 15 minutes;
- averages each local day (midnight to midnight, US Eastern);
- drops a day with fewer than **48** chlorophyll readings, as training did;
- scores each completed day automatically.

The last 30 days, the clock, today's partial sums and all calibration are kept in flash memory
(NVS), so a reboot loses nothing except the time it was off.

| Flag | Part | ESP32 pins | Library (Library Manager) |
|---|---|---|---|
| `USE_DS18B20` | DS18B20 waterproof temperature probe | data → **GPIO 4**, 4.7 kΩ from data to 3.3 V, red → 3.3 V, black → GND | OneWire, DallasTemperature |
| `USE_TSL2591` | TSL2591 light sensor (fluorometer) | SDA → **GPIO 21**, SCL → **GPIO 22**, VIN → 3.3 V, GND | Adafruit TSL2591 Library, Adafruit Unified Sensor |
| (with TSL2591) | Blue excitation LED | **GPIO 25** → 1 kΩ → NPN transistor base; LED + resistor on the collector side (do not drive a bright LED straight from the pin) | — |
| `USE_EZO_EC` | Atlas EZO-EC conductivity circuit, **I2C mode**, address 0x64 | SDA → **GPIO 21**, SCL → **GPIO 22** (shared with the TSL2591), VCC → 3.3 V, GND | none (Wire) |
| `USE_PH` | Analog pH module | Po → voltage divider (10 kΩ / 20 kΩ, 5 V → 3.3 V) → **GPIO 34**; module V+ → 5 V, G → GND | none |
| always | Alert relay module | IN → **GPIO 26**, VCC → 5 V (VIN pin), GND; set `RELAY_ACTIVE_LOW = true` for an opto relay | — |
| always | Alert light | the onboard LED on **GPIO 2** | — |
| `USE_WIFI` | Wi-Fi push alerts (ntfy.sh) + internet clock | — | none |

Notes on the sensors:

- **EZO-EC:** the EZO ships in UART mode. Switch it to I2C as in Atlas's datasheet: short PGND to
  TX while powering it up.
- **Salinity:** the sketch sets EZO temperature compensation to 25 °C, which means no compensation.
  The EZO then reports conductivity at the water's real temperature. The sketch converts that to
  salinity with PSS-78 using the DS18B20 temperature. **Without the DS18B20, salinity stays `nan`.**
- **pH:** pH is logged in the daily line but is **not** a model input.

Sensor commands:

| Command | Does |
|---|---|
| `read` | Takes one sample line now (not stored) |
| `date 2026-10-05 14:30` | Sets the clock (needed without Wi-Fi; the board has no battery-backed clock) |
| `blank` | With the cuvette full of filtered seawater: stores its signal as zero chlorophyll |
| `chlk <k>` | Sets µg/L per fluorometer count, from a dilution series against a sonde or lab value |
| `gain l\|m\|h\|x` | Sets the TSL2591 gain. Redo `blank` and `chlk` after changing it |
| `cal686`, `cal918` | pH probe in the 6.86 buffer, then in the 9.18 buffer. `cal` shows the calibration; `calclear` erases it |
| `wifi <ssid>`, `wifipass <password>`, `ntfy <topic>`, `ntfytest` | Wi-Fi alerts (`USE_WIFI 1`). Stored in NVS, never in the code |

How Wi-Fi alerts work:

- The buoy sends **harbor bulletins** (plain-language messages), each also printed as `MSG <title> | <text>`:
  - **Bloom WARNING** when the alert turns on: risk, today's chlorophyll, and suggested actions (shellfish growers:
    plan early harvest, hold seed; hatcheries: switch to stored or filtered intake; managers: start phytoplankton
    and toxin sampling), plus the honest false-alarm rate (about 1 per site per season, fork findings §31).
  - **All clear** when the risk drops below 0.45 again.
  - **Bloom detected** at a bloom onset: daily chlorophyll above 10 µg/L after 5 stored days at or below 10
    (the event definition of the harbor-warning test), so a bloom hovering around 10 is not announced every dip.
  - **Buoy check needed** when a day is dropped for too few readings (sensor, power or fouling problem).
- SENSOR days push every bulletin to `https://ntfy.sh/<topic>`. Demo `day` lines print them but never push.
- `site <name>` sets the name used in bulletins (e.g. `site Newport-Harbor`); it is kept in NVS.
- Install the ntfy app and subscribe to the same topic.
- ntfy topics are public, so pick a topic name nobody would guess.
- No board? `python replay_demo.py --sim --station B3 --start 2023-05-01 --days 150 --bulletins` prints the
  bulletin timeline a real season would have produced (same rules as the firmware).

## 6. Limitations: read before quoting results

1. **Climatology.** In training, `chl_climatology` is the station's average for the same 15-day
   window in *earlier years*. A new buoy has no earlier years.
   - The board uses the `clim <month> <value>` table if you load one. Good sources are the site's
     past data, or the fork's values for the nearest RIDEM station.
   - Otherwise it uses `nan`, which becomes the training median (9.2 µg/L).
   - Over the full B3 and F4 records, dropping the climatology changes the alert decision on
     **111 of 2,913** and **133 of 4,725** days (about 3 to 4%), with p shifts up to 0.38.
   - The month table is also coarser than the 15-day bins used in training.
2. **Chlorophyll scale.** The model was trained on RIDEM sonde chlorophyll (µg/L). A DIY
   fluorometer reads raw counts, so `blank` + `chlk` must turn those counts into
   **sonde-equivalent** µg/L. Calibrate against a sonde or a lab extraction; a dye dilution only
   is not enough.
   - If the scale is off by 2x, the 10 µg/L bloom line and every chlorophyll input are off by 2x.
   - The PC tool `predict_anywhere.py` quantile-rescales chlorophyll; the board does not.
   - The planned fix is a 2-4 week side-by-side next to a RIDEM or Narragansett Bay NERR sonde
     (plan §12 in `notes/mitigation/EXECUTION_PLAN.md`). `blank` + `chlk` are fitted from those daily
     means with a target of ±20%.
3. **No oxygen sensor.** `do` and `do_lag1` are always missing, so the model uses the training
   median (7.8 mg/L). Oxygen is one of the model's inputs, so expect somewhat weaker skill than the
   fork's published numbers.
4. **The first days are thin.** Several inputs need a minimum amount of history:
   - lags need 1 to 4 earlier days;
   - `chl_roll21_mean` needs 7;
   - the 6-day trend needs 2.

   Until then those inputs fall back to the training medians. Forecasts become comparable to
   training after about 3 weeks of complete days.
5. **No ON/OFF loop rules.** The relay simply follows today's alert. The alerter's rules (recheck
   every X days, C_ok, MAX_ON, T_off, floor, handover) are not ported yet. `controlHook()` in the
   sketch is the hook for them; see the TODO there and `hardware/alerter_uno/alerter_uno.ino`.
6. **Clock.** Without Wi-Fi the clock starts again from the last saved time after a power cut.
   Send `date` again after any long outage, or days will be stamped late.

## Regenerating after a model update

```bash
# in the fork (hab-bloom-predictor-narragansett), BASE env
~/anaconda3/python.exe src/deploy/export_c_model.py      # writes release/bloom_model.h
# copy it over hardware/buoy_esp32/bloom_model.h and keep the "COPIED, NOT EDITED" note on top, then here:
~/anaconda3/python.exe hardware/buoy_esp32/make_test_vectors.py
```

## Size

ESP32 Dev Module, esp32 core 3.3.12, all flags 0: 352,322 bytes flash (26%), 24,664 bytes RAM (7%).
With USE_EZO_EC + USE_PH + USE_WIFI: 1,128,844 bytes flash (86%; Wi-Fi + HTTPS is most of it), 52,456 bytes RAM.
The model tables take about 37 KB of flash.

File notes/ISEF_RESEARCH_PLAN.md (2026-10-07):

# Research Plan (ISEF Form 1A structure), rewritten 2026-10-07

Status: for review and signature by the Adult Sponsor and Direct Supervisor, Meghana Fernandez
(Forms 1, 1A, 1B; Form 3 and 6A alongside). No bench work starts before these are signed and the CSEF
Scientific Review Committee approves Forms 3 and 6A.

This replaces the 2026-09-05/19 plan, which described a magnetic clay-flocculation device. That device
was dropped on 2026-10-01 because it can't run unattended on the water; the bench now tests aeration
and low-dose hydrogen peroxide (`notes/mitigation/EXECUTION_PLAN.md`, "Plan change 2026-10-01"). The
old plan is in git history (before the 2026-10-07 commit). The CSEF registration text, limited to
1,000 words, is the "CSEF Research Plan" Google Doc; this file is the full version with the same
hypotheses.

## A. Rationale

Algal blooms in coastal waters cause severe hypoxia, toxic contamination of marine life, and
disruptions to marine ecosystems and local economies. Water-quality agencies find blooms by sampling
on a fixed schedule, so they usually act only after a bloom is visible, when treatment works least.
Operational forecasts (NOAA Lake Erie, Gulf of Mexico HAB-OFS, California C-HARM) cover a few places
and rely on satellites or circulation models. Continuous sensors now report chlorophyll fluorescence
every 15-60 minutes at thousands of sites, but no low-cost system uses those readings to forecast a
bloom and act on it automatically.

## B. Research question, hypotheses and engineering goals

**Question:** Can a low-cost autonomous device forecast algal blooms from daily sensor data and
trigger treatment early enough to reduce their peak?

**Forecasting hypothesis:** if the forecast uses daily sensor data, then it ranks bloom risk better
than a calendar (time-of-year) forecast in a pre-registered test (p < 0.05), because daily data
captures bloom starts that 3-weekly boat sampling misses.

**Treatment hypothesis:** if a treatment (aeration or low-dose hydrogen peroxide) is switched on
automatically when the forecast predicts a bloom, then treated tanks will have a lower or later bloom
peak than both untreated tanks and tanks treated only after the bloom becomes visible, without
harming non-target organisms (brine shrimp) or pushing algae below their normal levels, because
acting early stops growth before cell numbers are high.
- The pass marks are fixed in `notes/mitigation/00_CONTROL_LOOP.md`: aeration is judged on days held
  below the bloom threshold; peroxide on a ≥ 50% lower peak than untreated tanks and a larger cut than
  reactive treatment; non-target survival equal to untreated; never below 80% of the warm-up level.
- Also reported, with no pass mark: days to regrow after treatment stops, and whether peroxide hits
  small cells (about 2 µm) harder than large ones.

**Engineering goals:** a low-cost device (about $400 in parts) that runs the forecast on board and
matches the computer model's alerts (100% identical), measures chlorophyll within ±20% of a reference
after calibration, runs unattended for 14 days with no gaps in its log, and doses peroxide so the far
side of the tank reaches 0.8 ± 0.2 mg/L within 15 min while staying below 2.8 mg/L 50 cm from the
outlet within 5 min.

## C. Procedures

**Location and supervision.** Bench work at Bi-Cultural Hebrew Academy (Stamford, CT) under Direct
Supervisor Meghana Fernandez (M.S. Microbiology, UCLA; Adjunct Professor, UConn), who is present for
all chemical and culture work. Computational work is done at home on public data.

### C.1 Forecast (computational)
- **Device model:** gradient boosting trained on Narragansett Bay (RI DEM) fixed-site sondes
  (chlorophyll fluorescence, oxygen, temperature, salinity, summarized daily); it predicts whether
  chlorophyll exceeds the bloom level within 7 days. Alert threshold 0.45, chosen on validation data.
- **Long Island Sound model:** CT DEEP boat-survey data (50 stations, 1993-2025, lab-corrected
  chlorophyll), logistic regression with 35 features.
- **Testing:** each model is scored only on years it was not trained on (walk-forward), with
  thresholds chosen on validation data, and compared with a calendar forecast by AUC with a
  station-year bootstrap (2,000 resamples, one-sided p < 0.05), as pre-registered. Model-class
  alternatives (gradient boosting, neural networks, TabPFN) were tested under separate
  pre-registrations. The 2026 season is a pre-registered independent check
  (`notes/PROSPECTIVE_2026_PREREG.md`).

### C.2 Bench
1. **Seawater:** artificial sea salt in distilled water to salinity 27.5 (matched to the Sound), with
   nitrate, phosphate and silicate stocks and f/2 trace metals and vitamins; 12-15 °C; 12:12 light.
2. **Cultures:** non-toxic marine microalgae from NCMA (*Skeletonema*, *Thalassiosira weissflogii*,
   *Phaeodactylum tricornutum*, *Prorocentrum micans*, *P. triestinum*, *Micromonas pusilla*,
   *Nannochloropsis*), grown in f/2 medium.
3. **Aeration screen:** 500 mL cultures at four air flows (none; gentle, CO₂ only; 25 mL/min =
   0.05 vvm; 300 mL/min = 0.6 vvm, matching Sung & Gobler 2026) × 4 species × 3 replicates; 48 h on,
   48 h regrowth.
4. **Peroxide screen:** 250 mL flasks at 0, 0.8, 1.6, 3.2 and 6.4 mg/L H₂O₂ (3% H₂O₂ diluted to a
   0.1% working solution; 160 µL per 200 mL = 0.8 mg/L), plus three daily 0.8 mg/L pulses; sodium
   percarbonate at the same peroxide dose; sodium carbonate as a pH control; 3 replicates; counts at
   24, 48 and 72 h. Brine shrimp (*Artemia*) survival is the non-target check.
5. **Loop runs:** 10 L tanks, 3 per arm: A untreated; B forecast-triggered loop; C reactive
   (starts at 50% of the expected peak); D false alarm (loop triggered with no nutrients added).
   A 21-day low-nutrient warm-up, then a nutrient pulse starts the bloom (2-3 weeks), then 5 days of
   monitoring. Two pilot tanks confirm the culture blooms and set the expected peak.
6. **Loop control:** an Arduino reads chlorophyll (DIY fluorometer), temperature and pH, runs the
   forecast, and turns treatment on at a bloom probability of 0.45. It re-measures after each period
   and turns off when the forecast drops and chlorophyll is low and not rising.
   - Peroxide: 0.8 mg/L per pulse (8 mL of 0.1% per 10 L, calibrated peristaltic pump, inline
     dilution); a new pulse only if the residual is ≤ 0.5 mg/L; at most 3 pulses.
   - Aeration: air pump switched by a relay.
   - Automatic stops: peroxide above 2.8 mg/L, pH outside 7.6-8.6, dissolved oxygen below 4 mg/L,
     or chlorophyll below 80% of normal for 2 days.
   - Before the loop run, procedure P7 checks pump calibration, the controller logic and how the dose
     spreads through the tank (`notes/mitigation/PROCEDURES.md`).

### C.3 Risk and safety (Form 3; Form 6A)
- **Chemicals:** hydrogen peroxide 3% and 7% (up to 1 L), sodium percarbonate (up to 100 g), sodium
  carbonate, nutrient salts (sodium nitrate, sodium phosphate, sodium metasilicate), household bleach,
  90% acetone (up to 250 mL), water-test kit reagents. Hazards: eye and skin irritation or burns;
  percarbonate and nitrate are oxidizers; bleach releases toxic gas with acids or ammonia; acetone is
  flammable.
- **Activities and devices:** mains and 12 V pumps and grow lights near salt water (all mains devices
  on a GFCI; electronics above the water; unplug before reaching into a tank); soldering (lead-free,
  ventilated, iron unplugged after use).
- **Organisms:** non-toxic marine microalgae, Risk Group 1, handled at BSL-1 (Form 6A); brine shrimp
  (invertebrates) for toxicity tests. No humans, no vertebrates, no tissue, no toxic or pathogenic
  strains.
- **Precautions:** supervisor present; splash goggles, nitrile gloves and lab coat; no food or drink;
  small quantities; Safety Data Sheets read before first use; stocks labeled and dated; never mix
  bleach with acids, ammonia or peroxide; acetone only with ventilation and no flames.
- **Disposal:** peroxide-treated water is held until test strips read below 0.5 mg/L; all
  algae-containing water is disinfected with 10% bleach for 30 min and flushed down a lab sink;
  consumables are bleached and bagged; brine shrimp are frozen or bleached, never released. Nothing
  goes into the Sound, storm drains or the ground.

### C.4 Data analysis
- **Forecast:** AUC on held-out years, precision and lift at the validation-chosen threshold, and the
  paired bootstrap against the calendar forecast.
- **Bench:** peak chlorophyll, area under the chlorophyll curve, days below the bloom threshold,
  total treatment (hours ON or mg dosed), number of treatment episodes, brine shrimp survival and
  dissolved oxygen, compared between arms with Welch 95% confidence intervals on n = 3 tanks
  (t-intervals, t = 4.30). With n = 3 a result can be "consistent but underpowered", and it is
  reported that way.

## D. Bibliography

1. Anderson, D. M., Cembella, A. D., & Hallegraeff, G. M. (2012). Progress in understanding harmful
   algal blooms: paradigm shifts and new technologies for research, monitoring, and management.
   *Annual Review of Marine Science*, 4, 143-176.
2. Matthijs, H. C. P., et al. (2012). Selective suppression of harmful cyanobacteria in an entire lake
   with hydrogen peroxide. *Water Research*, 46, 1460-1472.
3. Randhawa, V., Thakkar, M., & Wei, L. (2012). Applicability of hydrogen peroxide in brown tide
   control: culture and microcosm studies. *PLOS ONE*, 7, e47844.
4. Sung, J., & Gobler, C. J. (2026). Mitigation of harmful algal bloom (*Margalefidinium
   polykrikoides*) intensity and toxicity via aeration processes. *Journal of Environmental
   Management*, 402, 129015.
5. Reichwaldt, E. S., Zheng, L., Barrington, D. J., & Ghadouani, A. (2012). Acute toxicological
   response of *Daphnia* and *Moina* to hydrogen peroxide. *Journal of Environmental Engineering*,
   138, 607-611.
6. Thoo, R., Siuda, W., & Jasser, I. (2020). The effects of sodium percarbonate generated free oxygen
   on *Daphnia*: implications for the management of harmful algal blooms. *Water*, 12, 1304.
7. Guillard, R. R. L. (1975). Culture of phytoplankton for feeding marine invertebrates. In W. L.
   Smith & M. H. Chanley (Eds.), *Culture of Marine Invertebrate Animals* (pp. 29-60). Plenum Press.
8. Connecticut Department of Energy and Environmental Protection. Long Island Sound Water Quality
   Monitoring Program data, 1993-2025.
9. Rhode Island Department of Environmental Management. Narragansett Bay Fixed-Site Monitoring
   Network data, 2005-2023.

## Not claimed
- That the device prevents blooms in open water: the test is in tanks; the target is enclosed or
  semi-enclosed water (harbors, shellfish beds, aquaculture pens, coastal ponds).
- That the device is field-ready, or safe without the false-alarm (arm D) data.
- Any result before it is measured.

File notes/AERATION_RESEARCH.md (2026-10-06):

# Aeration and oxygenation of estuarine water: practice, bottlenecks, and what a forecast-triggered prototype could do

Written 2026-09-14 from a web research pass (30+ fetches; research agent, this session).
Purpose: decide whether "forecast -> signal -> aerator" is a defensible tangible add-on for CSEF 2027.
Items marked *inference* are ours, not a source's. See notes/SCIENTIFIC_METHOD.md for how this connects to the model.

## 1. Who aerates estuarine or coastal water today

- **Rock Creek, MD (Chesapeake tributary), 1988-present.** Only long-running US tidal-estuary bubbler found. 800 m reach, 138 coarse diffusers, ~15,000 L/min air, ~74 ha influence. Runs June 1-Oct 1, daylight only; bottom water re-anoxifies "within one tidal cycle" when off. 2019 rebuild: two 213 m fine-bubble diffusers, 180 scfm, night shutdown for noise/energy. $285k install, ~$7k/yr, ~$1M replacement. Trigger: calendar. Effect: stopped H2S; increased methane venting (up to 1,500 umol/m2/d). [MD Sea Grant; Frontiers 2022; Maryland Reporter 2019]
- **Chesapeake main-stem proposal (2019, HydroLogics).** 16 O2 pipes, $10-20M build, ~$11M/yr electricity. Rejected on exchange, unproven plume physics, MeHg/N2O, fish-barrier grounds. EPA Bay Program: aeration only an add-on after nutrient cuts. Not built.
- **Baltimore Inner Harbor, Sept 2024 turnover.** ~24,000 fish dead; the National Aquarium wetland's small aerator acted as a localized refuge. Best real-world demo that a small aerator makes a *refuge*, not a fix. [WMAR]
- **Cardiff Bay, Wales (barrage-impounded lake).** GBP 3.4M (2000-01), compressors at five shore sites, ~800 bottom diffusers; statutory 5 mg/L DO floor checked by 9 continuous stations at 15 min; liquid-O2 barge backup ~5 t/day. 2023 minutes: 20-year-old system needs replacement, PhD studying reducing aeration. Not tidal. [BAM Nuttall; Cardiff Harbour Authority; Vale of Glamorgan minutes]
- **Salford Quays, Manchester (enclosed docks).** 16 Helixor air-lift mixers, shore compressor, 1986-90, with nutrient exclusion: lower bacteria/nutrients and "suppression of algal growth". 2010 renewal budget GBP 650k + 350k. [Radway 1988; Salford council]
- **Tidal Thames.** Two EA vessels (Thames Bubbler 1988, Thames Vitality 1997), each up to 30 t O2/day, ~GBP 250k/yr each. Trigger: reactive after storm overflows, DO analyzers on board, manual dispatch. Clearest operational, mobile, DO-triggered estuary program. [Servomex; gasworld]
- **Baltic BOX, Byfjorden SE, 2009-12.** Pumped oxic surface water into the anoxic basin (~2 m3/s pilot); deep O2 rose to ~110 umol/L. Full Baltic concept 10,000 m3/s, ~100 MW, ~2 bn SEK. Not implemented. [ISME J; phys.org; Marsys]
- **Savannah Harbor, GA.** Speece cones injecting 40,000 lb O2/day at two sites as dredging mitigation; pure-O2 injection into truly tidal water, permitted. [ECO2]
- **Hong Kong (Tolo/Victoria), Hood Canal.** No aeration programs found; pollution control / sediment bioremediation / monitoring instead.

## 2. Lake, pond and marina technology

- Diffused-air bubblers: ~1/2 hp per surface acre; $800-2,000 for 1-3 acres, $2-5k+ to ~9 acres (Kasco RobustAire RA1: 1/4 hp, 1-2 acres).
- Marina de-icers/bubblers (Kasco, Power House, Taylor Made): 1/4-2 hp, already permitted fixtures at CT marinas. *Inference:* the natural host for a prototype.
- Solar circulators (SolarBee/Medora, now Ixom): up to 10,000 gpm, 35-50 acres per unit; PA DEP 2004 flags mussel/barnacle cleaning in salt water.
- Hypolimnetic oxygenation (Speece cone, e.g. Camanche Reservoir 1993); destratification (Jordan Lake NC, USACE 2013: two platforms, 7.5 hp VFD motors).
- Nanobubbles (Moleaer): vendor claims 50% cyanobacteria reduction; no price published.
- **Does mixing suppress blooms?** Visser et al. 2016 (Aquatic Ecology 50:423-441): only for buoyant cyanobacteria, only if mixing is strong, deep and well distributed; standing crop often *increases* via nutrient mobilization. *Inference:* LIS/Narragansett summer blooms are diatoms/dinoflagellates, so mixing is a DO tool here, not bloom prevention.

## 3. Long Island Sound

No in-water aeration or mixing found for LIS or Stamford/Norwalk/Hempstead/Mamaroneck harbors. Only in-water engineering idea in the literature: Bowman's East River tidal locks. Strategy is the 2000/2001 nitrogen TMDL (58.5% cut by 2017) and CT DEEP's 2016 second-generation strategy. Hypoxic area: 208 sq mi (1987-99 mean) -> 83 sq mi (2021-25) -> 18.3 sq mi in 2025. Neither DEEP nor the Partnership mentions aeration.
Scale (*back-of-envelope*): ~65 km3 volume; 2021-25 hypoxic area = ~290 Rock Creek zones (1987-99 baseline ~730); a one-time 2 mg/L lift of a 5 m bottom layer over 215 km2 = ~2,200 t O2 = ~73 Thames-Bubbler-days, before sediment demand, at 3-5x Rock Creek's compressor depth.

## 4. Bottlenecks named by operators and papers

Reactive triggering (Thames after overflows; Rock Creek on a calendar). Energy and noise (Rock Creek night shutdown; Chesapeake $11M/yr; Baltic 100 MW). Tidal exchange (re-anoxifies in one tidal cycle). Side effects (methane, nutrient mobilization, MeHg/N2O, bubble curtains as fish barriers). Fouling and maintenance (barnacles on SolarBee; Cardiff replacement; Rock Creek $1M rebuild; DO-sensor fouling gives false low readings, In-Situ sells wipers for it). Regulatory framing: aeration is an add-on after load reductions.

## 5. Forecast- or sensor-triggered aeration that exists

- Aquaculture, setpoint-triggered, common: Eruvaka PondGuard (claims 20% energy saving), Reecotech (Vietnam), In-Situ RDO Trio -> PLC over Modbus. Boyd: $2,000-3,500 per 5 ha pond; energy savings alone do not pay back in 5 years. None use a forecast.
- Forecast-triggered, research only: 24 h DO forecast catching 91.8% of drops below 6 mg/L (Water 2026); 15-45 min and multi-hour ML forecasts; MPC in RAS holds DO within +/-0.4 mg/L.
- **No commercial product switches an aerator on a multi-day bloom forecast.** That is the gap.

## 6. Where a small device is plausible

Marinas, shellfish leases, small embayments, stormwater ponds. Vaudrey 2016: dawn hypoxia in inner LIS embayments (sensors 20 cm off bottom, 15 min, 8 embayments, 2014); N loads for 115 CT/NY embayments. CT DEEP logs menhaden kills Darien-New London from school-induced hypoxia. CT aquaculture ~$30M/yr, half oysters. Achievable claim: a measurable refuge patch (two DO loggers, one 1/4-1/2 hp aerator).

## 7. Regulatory (CT)

State: CT DEEP LWRD, Structures/Dredging/Fill; tracks = individual permit, Certificate of Permission (45/90 d), General Permits (90 d); 401 cert only if fill. Federal: USACE CT General Permit GP-41 (2021): GP 1 temporary structures (self-verification, removal within a season), GP 4 floats/misc structures, GP 6 utility lines, GP 16 aquaculture via CT Dept of Agriculture. *Inference:* a shore compressor + weighted air line + diffuser hung from an existing dock, seasonal and removable, is the easiest path.

## Forecast-triggered duty cycle (our number, 2026-09-14)

From the locked LIS test predictions (2023-2025, June-September station-visits): the model flags 15% of summer visits at threshold 0.50 (catching 60% of the visits followed by a bloom) and 7% at 0.60 (catching 48%). A Rock-Creek-style calendar runs 100% of the season. *Inference:* a forecast-triggered controller would run an aerator roughly one-seventh to one-fifteenth of the hours a calendar schedule does, with a corresponding cut in energy, noise and fouling exposure. Per-station share of summer visits flagged at 0.60: A4 0.57, B3 0.48, 02 0.44, C1 0.10.

## Bottom line

1. Sound-scale aeration is off the table (hundreds of Rock Creeks, tens of MW, no agency mentions it; nitrogen cuts already reduced hypoxia ~60%).
2. Aeration works and is operated today at hectare scale in enclosed/shallow water, or as mobile emergency oxygen; always as a DO tool, never bloom prevention.
3. Mixing does not suppress diatom/dinoflagellate blooms. Frame any device as pre-emptive DO support ahead of the post-bloom crash.
4. Every operational system is schedule- or setpoint-triggered. A forecast-to-relay controller on a marina de-icer or pond bubbler is a real gap and a feasible prototype.
5. Credible field test: refuge-patch experiment in a CT cove or marina slip, seasonal removable rig under DEEP COP/GP + USACE self-verification, with a grower or harbor commission as partner.

## Sources
- https://www.mdsg.umd.edu/fellowship-experiences/bubble-bubble-communitys-fix-bad-smells-offers-unique-research-opportunity
- https://www.frontiersin.org/articles/10.3389/fenvs.2022.866152/full
- https://marylandreporter.com/2019/07/01/bubbling-the-bays-dead-zone-breath-of-fresh-air-or-pipe-dream/
- https://www.wmar2news.com/local/heres-why-dead-fish-were-discovered-floating-in-baltimores-inner-harbor
- https://en.wikipedia.org/wiki/Water_oxygenation
- https://www.bam.com/en/press/press-releases/2000/11/nuttall-secures-ps34-million-cardiff-bay-aeration-scheme
- https://www.cardiffharbour.com/environmental-monitoring/
- https://www.valeofglamorgan.gov.uk/Documents/_Committee%20Reports/Cabinet/2024/24-02-08/Cardiff-Bay-Minutes.pdf
- https://onlinelibrary.wiley.com/doi/abs/10.1111/j.1747-6593.1988.tb01334.x
- https://services.salford.gov.uk/solar_documents/CSSLMR221110D.DOC
- https://www.servomex.com/news/biologically-dead/
- https://www.gasworld.com/story/servomex-uses-oxygen-tech-to-help-inject-life-back-into-the-thames/
- https://www.nature.com/articles/ismej2014172
- https://phys.org/news/2011-05-oxygenation-life-baltic-sea.html
- https://www.marsys.se/baltic-deepwater-oxygenation-box/
- https://eco2tech.com/technical-library/o%E2%82%82-to-the-rescue-savannah-harbor-expansion-project-dissolved-oxygen-mitigation/
- https://www.tandfonline.com/doi/full/10.1080/10402381.2019.1648612
- https://americanaeration.com/products/kasco-ra1-robust-aire-diffused-aeration-system
- https://www.livingwateraeration.com/collections/pond-aerators
- https://www.savvyboater.com/de-icers-ice-eaters/
- https://files.dep.state.pa.us/water/Drinking%20Water%20and%20Facility%20Regulation/lib/watersupply/solarbee.pdf
- https://www.wateronline.com/doc/solarbee-v18-solar-powered-long-distance-0001
- https://www.moleaer.com/en-us/industries/lakes-ponds
- https://agris.fao.org/search/en/records/65df194d7c7033e84beccd19
- https://www.sciencedirect.com/science/article/abs/pii/B9780127518015500101
- https://portal.ct.gov/DEEP/Water/LIS-Monitoring/LIS-Hypoxia-and-Nitrogen-Reduction-Efforts
- https://lispartnership.org/about/our-mission/management-plan/hypoxia/
- https://seagrant.uconn.edu/2025/12/05/hypoxia-in-long-island-sound-drops-to-record-low-in-2025/
- https://in-situ.com/us/pond-aquaculture
- https://agriculture.cioreviewindia.com/vendor/2020/eruvaka_technologies
- https://reecotech.com.vn/en/continuous-monitoring-solution-for-dissolved-oxygen-in-shrimp-farming/
- https://www.globalseafood.org/advocate/automated-dissolved-oxygen-sensing-and-aerator-activation-in-aquaculture/
- https://doi.org/10.3390/w18131618
- https://link.springer.com/article/10.1007/s43926-025-00201-w
- https://link.springer.com/article/10.1007/s10499-026-02504-3
- https://vaudrey.lab.uconn.edu/wp-content/uploads/sites/1663/2017/02/Vaudrey_R-CE-34-CTNY_FinalReport_2016.pdf
- https://portal.ct.gov/DEEP/News-Releases/News-Releases---2020/Menhaden-Fish-Kills-Reported-Along-Connecticut-Shoreline
- https://www.foodmanufacturing.com/supply-chain/news/21614872/connecticut-oyster-industry-thriving-25-years-after-nearly-disappearing
- https://portal.ct.gov/DEEP/Coastal-Resources/Coastal-Permitting/Overview-of-the-Connecticut-Coastal-Permit-Program
- https://portal.ct.gov/-/media/DEEP/Permits_and_Licenses/Land_Use_Permits/LWRD/USACEctGeneralPermit2021
- https://www.nae.usace.army.mil/Missions/Regulatory/State-General-Permits/Connecticut-General-Permit/

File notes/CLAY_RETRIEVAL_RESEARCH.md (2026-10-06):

# Flocculation + retrieval of algal floc: what has actually been done

Written 2026-09-15 from a web research pass (~55 fetches; research agent, this session; Step 1 of the device plan). Companion to notes/CLAY_FLOCCULATION_RESEARCH.md (clay that sinks) and notes/AERATION_RESEARCH.md. Four primary reports were read in full (FDEP INV002 Lake Jesup, INV003 ARP Pond, INV024 Indian River Lagoon; PJOES magnetic-clay paper) plus USGS SIR 2024-5091, the NOWPAP HAB countermeasures booklet, PNNL-35507 and FDEP Emergency Final Order 18-1100. Where only an abstract or snippet was reachable it says so. Computed values are marked [inferred].

## 1. Magnetic modified clay / magnetic flocculants

**Fan et al. 2026, Pol. J. Environ. Stud. 35(3):4139-4150 (PJOES), magnetic bentonite/kaolinite + CPAM.** Full text read. Synthesis: 1 g bentonite (200 mesh) in 100 mL distilled water, sonicated 10 min; add 1.96 g FeCl3.6H2O + 0.9 g FeCl2.4H2O, stir 10 min; pH 10-11 with NH3.H2O; 60 C for 3 h; separated with a permanent magnet; washed 3x ethanol/water; dried 65 C. Same recipe for kaolinite. [inferred: Fe3+:Fe2+ ~1.6:1 molar; theoretical Fe3O4 ~0.84 g per 1 g clay.] Species: Microcystis aeruginosa (freshwater), 50 mL batches. Optimum: magnetic clay:CPAM 1:1, pH 2, 150 rpm, 10 min, 0.8 g/L magnetic bentonite or 0.4 g/L magnetic kaolinite; Box-Behnken optimum 0.206 g/L, 12.9 min, 170.6 rpm -> 92.13% measured. Floc D50 65-68 um vs 2.4 um cells. NOT reported: magnetic field strength, capture time, recovery fraction of floc or clay, reuse cycles, residual Fe, cost. Removal was measured after settling, not after magnetic capture [inferred from Methods]; reusability listed as future work.

**Ma et al. 2019, J. Cleaner Prod. 248:119276, Fe3O4/CPAM on algae-laden raw water.** Chlamydomonas; >97% Chl-a, 87% turbidity at 1.2 mg/L Fe3O4/CPAM, mass ratio 1.5:1, pH 4-9; recovery and reuse tested but values paywalled. Freshwater.

**Magnetic buoyant beads, J. Environ. Chem. Eng. 2023 (10.1016/j.jece.2023.110170).** Fe3O4 on closed-cell perlite, CPAM pre-flocculant. Removal >97.6% for Chlorella, Microcystis, Anabaena; CPAM raised removal 27-46 points over beads alone; beads + algae "easily separated by applying a magnetic field." Freshwater; no dose, field strength, recovery % or reuse data reachable.

**Iron-oxide-immobilized bioflocculants, ESPR 2026 (PMID 42237017).** Microcystis, ~96% at pH 7, 37 C, 120 rpm, 60 min settling; reusable 4 times. Freshwater.

**Liu, Li & Zhang 2009, Water Sci. Technol.** 4 mg/L Fe3O4 + 1.6 mg/L chitosan: >99% cells, 73.9% TN; "ionic strength had a negative effect on removal efficiency" (warning for seawater).

**Reuse/recovery (magnetic flocculants generally, review snippets, verify before quoting):** particle recovery 84-97.5% via sonication + alkali; 5 cycles typical, 10 with bare Fe3O4; CPAM-grafted Fe3O4 lost efficiency sharply on reuse. Magnetite detaches from flocs at 1,500 Oe or 1,500-2,000 g. Energy/cost (topic summary, unverified): low-gradient magnetic separation 0.05-0.1 kWh/m3; $0.13/m3 at 300 mg/L particles vs $0.52/m3 for HGMS at 50 mg/L.

**Marine/seawater, explicit answer:** No magnetic clay (Fe3O4-on-kaolinite/bentonite) study used seawater or a marine HAB species; all of the above are freshwater. Magnetic materials used in seawater: (a) Japan, Suga 1982 (lab): Fe3O4 + FeCl3 powders + flocculant through a magnetic separator, >80% removal of Chattonella, needing >=10 g iron powder per litre; environmental impacts "unknown" (NOWPAP). (b) Natural magnetic sphalerite, J. Hazard. Mater. 2017: Chattonella marina removed at 1-2 g/L, better at >25 C, salinity >30, pH <7.5; "excellent stability after magnetic recycling" (no cycle count). (c) Cerff et al. 2012: silica-coated magnetic particles, >95% separation of marine Phaeodactylum and Nannochloropsis cultures, HGMS. (d) Hu et al. 2013: naked Fe3O4 120 mg/L, >95% of Nannochloropsis maritima in 4 min, medium recycled 5x. All beaker scale; none on Karenia, Prorocentrum, Skeletonema, Alexandrium or Heterosigma; none in a natural bloom. IOCAS modified-clay work and its spraying patent contain no magnetic or recovery component.

## 2. Flocculation + DAF for blooms in open water

**USACE HABITATS / AECOM.** July 2019, Lake Okeechobee: three weeks, 100 gpm pilot; "100 million gallons a day" was an aspiration (NPR). Coagulant reported: aluminum chlorohydrate (ACH) 30-50 mg/L (unverified in the bot-blocked PDF). Shipboard prototype 400 gpm. Chautauqua Lake NY, Aug-Sep 2020: 205,000 gal treated -> 700 gal algae paste; DAF + ozone + screw press; each module "up to 2 MGD". USGS SIR 2024-5091 techno-economics for the 90-day 2018 event: N+P valued at $2.72/lb; removal 1,078-4,198 lb N+P/day; capex $674k-$1.04M; O&M $3.9-7.3M; net benefit -$2.1M to +$0.8M; "demand has not been demonstrated" for biomass products.

**FDEP Innovative Technology grants (AECOM Hydronucleation Flotation Technology, reports read in full):**
- Lake Jesup (INV002), $1.6M, 100 gpm barge, Sept 2021-May 2022: 388.75 h, 2.42M gal treated, 6,595 gal slurry (76% to a WWTP). Dose 40 mg/L ACH + 2 mg/L polyacrylamide; recycle 27-30%; 1.6-2 skims/h. Removal: Chl-a 85% (132 -> 22 mg/m3), TSS 83%, TP 85%, TN 43%. Energy 5.88 kW, 2,290 kWh [inferred 0.25 kWh/m3]. Effluent failed several chronic Ceriodaphnia tests, attributed to raw lake water. Scale-up cost: $739/lb TP and $54/lb TN at 1 MGD ($319/$23 at 40 MGD); capex $1.9M (1 MGD) to $43.3M (40 MGD). Meeting the in-lake TMDL share needs 40 MGD running 24/365.
- ARP Pond, Tallahassee (INV003), $1.65M, 1 MGD unit, Nov 2021-Jun 2022: 480 h on 79 days, 14.5M gal, 16,720 gal slurry. 20 ppm ACH + 1 ppm polymer: Chl-a 80% mean/94% median, TP 80/88%, TN 40/45%. Energy 18.68 kW [inferred 0.16 kWh/m3]. No acute/chronic toxicity.
- **Indian River Lagoon, brackish (INV024), $999k, 700 gpm barge, Sep-Nov 2023, salinity 19-20 ppt:** 191.5 h, 4.03M gal treated, only ~255 gal slurry at 8% solids, landfilled. ACH 18.7 mg/L + anionic polyacrylamide 0.7 mg/L; recycle 45% vs 20-30% in freshwater because "high salinity reduces air saturation as well as the mobility of bubbles and flocs"; one skim per 55,085 gal. Removal: **Chl-a 21%, TP 26%, TN 0%**, turbidity 75%; effluent DO +1.12 mg/L; TSS *higher* in effluent from wave-induced float-blanket carryover. Full-scale estimate $1.96M/yr, $0.88 per 1,000 gal. **The only saline DAF-harvest field trial found, and the closest analogue to Long Island Sound.**
- Lake Agawam NY, Oct 2019 (2 weeks, 120 gpm): >90% Chl-a, microcystins and TP; >80% TSS and TN; >$9M then secured for three 1 MGD harvesters.
- Lee County 2018 emergency vacuum removal (AECOM): $850k; 115,000+ gal slurry by 23 tankers; liquids to an RO plant then deep well, solids to landfill.
- Pahokee Marina/Franklin Lock 2021: $1M total.

**Chinese lakes.** Taihu wet-algae salvage 0.8 Mt (2008) to 1.6 Mt (2016); >10 Mt wet since 2007; >10,000 t dry powder. Wuxi: 14 bases up to 66,500 t/day. Bionic salvage platform 12 x 11 m, ~$290k, "<0.05 yuan per tonne of water". Dianchi harvest boats: CPAM 0.5-2 mg/L + 35 um rotary drum filter, >95% biomass removal in a 20,000 m3 enclosure, effluent Chl-a <8 ug/L, 0.053 kWh/m3 (PMID 33792846). Slurry 96% water.

**Seawater DAF at desalination intakes.** Li et al. 2026 (pilot): 0.5 mg/L NaClO pre-oxidation, 12 mg/L PAC, 0.2 mg/L cationic PAM; DAF + sand filter >95% algae. Villacorte et al. 2015: >75% with inline FeCl3.

**Microalgae DAF harvesting benchmarks.** Ton-scale DAF (5 m3/h) + screw press: 93% harvest, 1.7 kWh/m3 (PMID 39603474); ballasted DAF 99% at 0.04 kWh/m3; Chlorella dispersed-air flotation 98.7% with 40 mg Al3+ + 60 mg CTAB per g biomass, ~700 um bubbles, 15 min (PMC5717653).

**US 9,809,464 (Bryan, 2013):** pontoon boat with serial DAF channels, scum trough, diffused air; no coagulant dosing, no throughput, no field data. **ERDC RAFT** (TR-23-6): xanthan gum + CPAM + microbubbles in 14,000 gal ponds raised surface phycocyanin 5 -> 30 RFU; 2022 field demo formed a surface layer within 30 min.

## 3. Buoyant / floating flocculants

- Self-branched chitosan + CaO2@PEG (Carbohydr. Polym. 2021): released O2 floats flocs; reduced DO depletion and TP; zebrafish-biocompatible. No dose/% reachable.
- Chitosan-coated fly-ash cenospheres (ESPR 2020): 0.3-0.7 g/L, 98.5% Microcystis, >90% in 5 min.
- Fe3O4/closed-cell perlite (section 1) combines buoyancy and magnetism.
- Recovery in all three is skimming the floating layer; none reports a recovered-fraction figure. All freshwater.

## 4. Surface skimmers and booms

AECOM used oil-spill-type skimmers at Pahokee Marina and vacuum trucks in Lee County. Taihu operates the only routine large-scale skimming fleet. Lake Erie: Ohio Sea Grant says no practical harvest exists and cost "would be astronomical". Bycatch: FDEP trials tested effluent toxicity (mysid, silverside, Ceriodaphnia, fathead minnow) but reported no organism bycatch counts; no permit condition on bycatch found.

## 5. Sunk vs retrieved floc outcomes

- PAC-kaolinite (MCII) on Karenia, 80 L mesocosms (PMC12656167): 0.2 g/L; 91% at 5 h; sediment brevetoxin 191 -> 56 ng/g by 72 h; clams 5.1x Al, no mortality; DO "within normal ranges"; harvesting not evaluated.
- 1,400 L mesocosms, Harmful Algae 2024 (PMID 38705612): 0.2 g/L MCII; 57% at 8 h, 95% at 48 h; crab, urchin, clam responses no different from untreated.
- EPA ECOHAB final report: resuspended clay at 0.25 g/L cut clam growth ~90% while sedimented clay had no effect; settled floc retained brevetoxin after 96 h; PAC-treated clay is "fluffy" and easier to resuspend.
- Korea NFRDI: 5-year benthic survey in sprayed areas found no change (NOWPAP). WHOI mesocosm: benthic abundance +121% vs +56% control.
- Chitosan-soil column study (Frontiers 2018): sediment TN improved only when an O2-loaded zeolite cap was added; bare floc did not improve it.
- Floc size vs oxygen (Water Res. 2026, PMID 41547202): macroflocs >200 um consume less O2 per mass than <50 um flocculi; tidal shear breaks flocs into small, oxygen-demanding particles. Relevant to LIS.
- Harvesting side: IRL harvester effluent DO rose 1.12 mg/L. **No study directly compares bottom DO or sediment nutrients after sunk floc versus harvested floc.**

## 6. Nutrient export accounting

- PNNL-35507 (AECOM-harvested biomass): Lake Jesup slurry ash 33% dry, protein 32%, lipid 2%; process-model feed N 3.1 wt% AFDW, P 0.3 wt%; HTL biocrude minimum selling price $4.65-12.95/GGE.
- Dried Taihu cyanobacteria N 11.4%; ~50% protein.
- Wet-to-dry: DAF slurry 8% solids (IRL); Taihu station slurry 96% water; Korean DAF sludge 90% -> 82.6% after drainage.
- Fate: WWTP (Jesup, ARP), landfill (IRL, Lee, Taihu historically), compost (Taihu), HTL biocrude (HABITATS), fish feed trials.
- Crediting: no case found where harvested N or P was formally credited to a TMDL or traded; USGS values removed N+P at $2.72/lb while noting no demonstrated market.

## 7. Stats table

| System | Medium | Flocculant, dose | Retrieval | Removal | Recovery | Throughput | Cost | Energy | Time | Scale | Source |
|---|---|---|---|---|---|---|---|---|---|---|---|
| Magnetic bentonite+CPAM (PJOES 2026) | fresh | 0.206 g/L + CPAM 1:1, pH 2 | magnet (lab); settling measured | 92% cells | n/r | 50 mL | n/r | n/r | 13 min | beaker | pjoes.com |
| Fe3O4/CPAM (JCP 2019) | fresh | 1.2 mg/L, 1.5:1 | magnet | >97% Chl-a | tested, n/r | beaker | n/r | n/r | n/r | beaker | S0959652619341460 |
| Fe3O4/perlite beads (JECE 2023) | fresh | CPAM 80 mg/L | float + magnet | 97.6-98% | n/r | beaker | n/r | n/r | n/r | beaker | S2213343723009090 |
| Fe3O4-bioflocculant (ESPR 2026) | fresh | pH 7, 120 rpm | magnet | ~96% | 4 reuses | beaker | n/r | n/r | 60 min | beaker | PMID 42237017 |
| Magnetic sphalerite (JHM 2017) | marine | 1-2 g/L | magnet | high | recyclable | beaker | n/r | n/r | n/r | beaker | PMID 27847251 |
| Japan iron powder (Suga 1982) | marine | >=10 g Fe/L + flocculant | magnetic separator | >80% Chattonella | n/r | lab | n/r | n/r | n/r | lab | NOWPAP |
| HABITATS Okeechobee 2019 | fresh | ACH 30-50 mg/L (unverified) | DAF skim + ozone | n/r | n/a | 100 gpm | USGS scenario $4.6-8.4M/90 d | n/r | 3 wk | pilot | fox4now; USGS |
| HABITATS Chautauqua 2020 | fresh | organic flocculants | DAF + screw press | n/r | 700 gal paste / 205,000 gal | 400 gpm | see USGS | n/r | 5 d | pilot | dvidshub |
| AECOM Lake Jesup 2021-22 | fresh | ACH 40 + PAM 2 mg/L | DAF, 1.6-2 skims/h | Chl-a 85%, TP 85%, TN 43% | 6,595 gal slurry | 100 gpm | $739/lb TP, $54/lb TN (1 MGD) | 0.25 kWh/m3 [inf] | 389 h | pilot barge | INV002 |
| AECOM ARP Pond 2021-22 | fresh | ACH 20 + PAM 1 ppm | DAF | Chl-a 80-94%, TP 80-88% | 16,720 gal slurry | 1 MGD | $1.65M project | 0.16 kWh/m3 [inf] | 480 h | pilot | INV003 |
| **AECOM IRL 2023** | **brackish 19-20 ppt** | ACH 18.7 + anionic PAM 0.7 mg/L | DAF, 1 skim/55,085 gal | **Chl-a 21%, TP 26%, TN 0%** | 255 gal at 8% | 700 gpm | $0.88/1,000 gal; $1.96M/yr | 100 kW genset | 192 h | pilot barge | INV024 |
| Lee County 2018 vacuum | fresh/estuarine | none | vacuum trucks | n/r | 115,000+ gal | 30,000 gal/weekend | $850k | n/r | Aug-Sep | emergency | leegov.com |
| Taihu salvage fleet | fresh | none/flocculant at stations | skimmer boats + stations | n/r | 0.8-1.6 Mt wet/yr | 66,500 t/day (Wuxi) | $290k/platform | n/r | year-round | full | PMC8538822; MEE |
| Dianchi flocculation-drum boat | fresh | CPAM 0.5-2 mg/L | 35 um drum filter | >95% biomass | n/r | 20,000 m3 enclosure | n/r | 0.053 kWh/m3 | n/r | field | PMID 33792846 |
| Desal DAF (Li 2026) | marine | PAC 12 + PAM 0.2 mg/L + NaClO | DAF float | >95% w/ sand filter | n/a | pilot | n/r | n/r | n/r | pilot | PMID 42470165 |
| DAF + screw press (2024) | fresh culture | n/r | DAF | 93% | 11.9% cake | 5 m3/h | n/r | 1.7 kWh/m3 | n/r | ton-scale | PMID 39603474 |
| Korea loess spraying | marine | 100-400 g/m2 | none (sinks) | ~80% Cochlodinium (lab) | none | vessel | $210k/vessel | n/r | 30-40 min intervals | full | NOWPAP |
| MCII Karenia mesocosm | marine | 0.2 g/L PAC-kaolinite | none (sinks) | 91% at 5 h; 95% at 48 h | none | 80-1,400 L | clay ~$600/t + $100/t shipping | n/a | n/a | mesocosm | PMC12656167; WHOI |

## 8. Regulatory

- Florida 2018: Executive Order 18-191 and FDEP Emergency Final Order 18-1100 suspended procurement and employment statutes for emergency response; they did not waive water-quality or dredge/fill permits. Lee County's removal plan was separately approved by FDEP.
- Lake Jesup harvesting: F.A.C. 62-330.485 (environmental restoration general permit), a USACE "No Permit Required" determination, and an FDEP Industrial Wastewater/NPDES permit for returning treated water; the barge operated only "within a FDEP-permitted area". ARP Pond likewise.
- USACE HABITATS authority: WRDA 2018 research authorisation.
- Clay: China listed modified clay as a standard method in 2014 guidelines; Korea disperses loess on NFRDI alerts; Florida clay trials use permitted demonstration sites. **No permitting document distinguishes removal from deposition of clay or floc in coastal water**; the Florida DAF permits treat harvesting as an industrial discharge plus restoration activity.

## 9. What has never been done

1. Magnetic modified clay in seawater, on any marine HAB species, or beyond a beaker.
2. Measurement of the recovered fraction of clay or floc after magnetic capture in any HAB study (PJOES measured settling, not capture).
3. Any flocculation-plus-retrieval trial in tidal or wave-exposed water other than the 2023 IRL barge, whose float blanket broke up in waves.
4. Forecast-triggered, low-density pre-emptive dosing; every deployment was reactive to a visible bloom.
5. A controlled comparison of bottom DO, sediment nutrients or benthic fauna after sunk versus harvested floc.
6. Formal TMDL or nutrient-credit accounting for harvested bloom biomass.
7. Residual Fe/Al measurements after magnetic-clay treatment.

## Bottom line

- Magnetic clay works on freshwater Microcystis at 0.2-0.8 g/L with CPAM, but no paper reports the magnet, capture time, recovered fraction or reuse loss, and none has touched seawater; the only seawater magnetic data are 1982 Japanese lab work (>=10 g Fe/L) and a 2017 magnetic-sphalerite study at 1-2 g/L.
- Flocculation + DAF harvesting is real and measured: 80-94% Chl-a and TP removal in freshwater at 20-50 mg/L ACH + 1-2 mg/L polymer, 0.16-0.25 kWh/m3, but $319-739 per lb TP.
- The single brackish deployment (IRL 2023, 19-20 ppt) collapsed to 21% Chl-a and 0% TN removal because salinity cut bubble efficiency and waves broke the float blanket: the closest analogue to Long Island Sound and a cautionary result.
- "100 million gallons a day" was an aspiration; pilots ran 100-700 gpm; USGS finds net benefit between -$2.1M and +$0.8M for a 90-day event.
- Sunk PAC-clay floc carries toxin and aluminium to sediment without acute mortality; nobody has measured whether retrieving the floc changes bottom oxygen.
- Harvested biomass is 33-44% ash, ~3% N and 0.3% P dry, 8% solids wet; disposal, not nutrient credit, is the current end point.
- Gaps 1-5 are open and small enough for a bench-to-mesocosm science-fair design.

## Sources
- https://www.pjoes.com/Experimental-Removal-of-Microcystis-aeruginosa-nby-Magnetic-Clay-Minerals-Synergized,205257,0,2.html
- https://www.sciencedirect.com/science/article/abs/pii/S0959652619341460
- https://www.sciencedirect.com/science/article/abs/pii/S2213343723009090
- https://pubmed.ncbi.nlm.nih.gov/42237017/ ; https://pubmed.ncbi.nlm.nih.gov/19342803/ ; https://pubmed.ncbi.nlm.nih.gov/27847251/ ; https://pubmed.ncbi.nlm.nih.gov/26609948/ ; https://pubmed.ncbi.nlm.nih.gov/22705536/ ; https://pubmed.ncbi.nlm.nih.gov/23639490/
- https://www.sciencedirect.com/science/article/pii/S2211926425004515 ; https://pubmed.ncbi.nlm.nih.gov/29968210/ ; https://www.sciencedirect.com/topics/engineering/gradient-magnetic-separation
- https://cearac.nowpap.org/nowpap/wp-content/uploads/2023/11/HAB_Booklet.pdf
- https://patents.google.com/patent/US10822258B2/en ; https://patents.google.com/patent/US9809464
- https://www.npr.org/2019/07/29/745666501/a-new-old-way-to-combat-toxic-algae-float-them-up-then-skim-them-off
- https://www.fox4now.com/news/protecting-paradise/u-s-army-corps-partners-with-private-sector-on-algae-cleanup-project
- https://www.dvidshub.net/news/380902/erdc-reports-chautauqua-lake-habitats-research-results
- https://extapps.dec.ny.gov/docs/water_pdf/nysdecusacehabwebf.pdf ; https://apps.dtic.mil/sti/trecms/pdf/AD1150054.pdf
- https://www.erdc.usace.army.mil/Portals/55/CERL/HABITATS/HABITATS%20Pilot%20Reaserch%20Study-%20ERDC%20TR-20-1.pdf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
- https://ansrp.el.erdc.dren.mil/pdfs/gantt-pdfs/2024_Internal/05_Clinton_Cender_RAFT_FS.pdf
- https://pubs.usgs.gov/sir/2024/5091/sir20245091.pdf
- https://www.wateronline.com/doc/will-dissolved-air-flotation-fix-harmful-algal-blooms-0001
- https://floridadep.gov/owper/water-policy/content/innovative-technology-harmful-algal-blooms-final-reports
- https://floridadep.gov/sites/default/files/INV002.pdf ; https://floridadep.gov/sites/default/files/INV003.pdf ; https://floridadep.gov/sites/default/files/INV024.pdf
- https://www.hometownnewstc.com/news/aecom-demonstrates-algae-removal-system-in-indian-river-lagoon/article_970bafe2-57dd-11ee-bf30-37f39e686aab.html
- https://www.controlglobal.com/manage/sustainability/article/33013233/clearing-harmful-algal-bloom
- https://www.27east.com/southampton-press/news/government-news/article_457ddfd7-7bbc-599c-a9b4-f25b65fe7464.html ; https://www.danspapers.com/2019/10/combating-harmful-algal-blooms-in-lake-agawam/ ; https://www.southamptontownny.gov/1701/Lake-Agawam-Algae-Harvesting-Phase---SH-
- https://www.leegov.com/waterqualityinfo/bluegreenalgae
- https://bluegreenwatertech.com/post/florida-spent-1-million-on-toxic-algae-in-caloosahatchee-pahokee-marina ; https://www.lakeonews.com/stories/six-different-companies-to-try-to-clean-lake-o,84080
- https://pmc.ncbi.nlm.nih.gov/articles/PMC8538822/ ; https://pmc.ncbi.nlm.nih.gov/articles/PMC5684341/
- https://english.mee.gov.cn/News_service/media_news/201704/t20170411_409623.shtml ; http://english.scio.gov.cn/chinavoices/2025-03/14/content_117765961.html ; https://www.scmp.com/news/china/science/article/3189608/chinese-scientists-clear-blue-green-algae-bloom-massive-lake
- https://pubmed.ncbi.nlm.nih.gov/33792846/ ; https://pubmed.ncbi.nlm.nih.gov/42470165/
- https://darchive.mblwhoilibrary.org/bitstream/1912/7240/1/2015_Villacorte_etal_SWRO_HABs_accepted%20manuscript.pdf
- https://pubmed.ncbi.nlm.nih.gov/39603474/ ; https://pmc.ncbi.nlm.nih.gov/articles/PMC5717653/
- https://pubmed.ncbi.nlm.nih.gov/33673989/ ; https://pubmed.ncbi.nlm.nih.gov/32440871/
- https://pmc.ncbi.nlm.nih.gov/articles/PMC12656167/ ; https://pubmed.ncbi.nlm.nih.gov/38705612/
- https://cfpub.epa.gov/ncer_abstracts/index.cfm/fuseaction/display.abstractDetail/abstract_id/1014/report/F
- https://www2.whoi.edu/site/andersonlab/current-projects/florida-clay-mitigation/
- https://coastalscience.noaa.gov/project/application-of-clay-flocculation-for-removal-of-karenia-brevis-cells-and-toxins-in-southwest-florida-coastal-waters/
- https://mote.org/news/article/rapid-test-of-red-tide-mitigation-strategy-deployed-in-sarasota ; https://www.sarasotamagazine.com/news-and-profiles/2021/07/clay-focculation-red-tide ; https://hoodline.com/2026/04/sarasota-science-squad-takes-big-swing-at-red-tide-menace/
- https://www.sciencedirect.com/science/article/abs/pii/S1568988303000416
- https://www.frontiersin.org/journals/environmental-science/articles/10.3389/fenvs.2018.00060/full
- https://pubmed.ncbi.nlm.nih.gov/41547202/ ; https://pubmed.ncbi.nlm.nih.gov/29286322/ ; https://pubmed.ncbi.nlm.nih.gov/39567062/
- https://www.pnnl.gov/main/publications/external/technical_reports/PNNL-35507.pdf
- https://pmc.ncbi.nlm.nih.gov/articles/PMC9233212/ ; https://www.sciencedirect.com/science/article/abs/pii/S2211926425005181
- https://floridadep.gov/sites/default/files/18-1100_0.pdf ; https://floridadep.gov/ogc/ogc/content/2018-final-orders
- https://www.floridadisaster.org/news-media/news/20180709-gov.-scott-issues-emergency-order-to-combat-algal-blooms-in-south-florida/
- https://www.law.cornell.edu/regulations/florida/Fla-Admin-Code-Ann-R-62-330-485
- http://english.scio.gov.cn/chinavoices/2018-11/28/content_74218061.htm
- https://www.epa.gov/chesapeake-bay-tmdl/trading-and-offsets-chesapeake-bay-watershed

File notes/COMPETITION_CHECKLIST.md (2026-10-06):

# Competition checklist (2026-27 season) — written 2026-09-05

Fair: Connecticut Science & Engineering Fair (CSEF), ISEF-affiliated.
Entry type: first-time entry (no Form 7 continuation). Project category:
Environmental Engineering or Earth & Environmental Sciences (computational).
Adult sponsor: **Meghana Fernandez** (also Direct Supervisor; chosen 2026-10-04). Westhill teacher still needed to register the school by Oct 31.

## Dates (from the CSEF site, screenshot 2026-09-05)

| Date | What | Owner | Status |
|---|---|---|---|
| Sept 12 | Ask counselor to name a science teacher as adult sponsor | Vihaan | **OVERDUE** as of 2026-09-18; nudge drafted in notes/SPONSOR_ASK.md |
| Sept 19 | Fallback: any faculty member agrees to sponsor | Vihaan | due tomorrow; cold ask drafted in notes/SPONSOR_ASK.md |
| **Sept 25** | **HARD STOP: Forms 1A, 1, 3, 1B signed.** No hands-on work before this (notes/LAB_PROTOCOL.md s1) | Vihaan + sponsor + supervisor | open |
| Sept 28 | First hands-on work: build the rake, jar rig, controller | Vihaan | blocked by Sept 25 |
| **Oct 31** | **A Westhill teacher/staff member submits the CSEF school registration and buys a $50 project spot** (registering through school, decided 2026-10-04) | teacher + Vihaan | open: asked chem teacher Ms. Dodita who handles it, 2026-10-04; follow up Oct 7 if no reply |
| **Dec 1** | **High-school registration closes 11:59 pm**: online form + research plan + Form 2A + release form + any SRC forms (Form 3) | Vihaan | open |
| Feb 15 | High-school projects selected by school fairs due 11:59 pm | Vihaan | open |
| Feb 25 | Upload portal opens | Vihaan | open |
| mid-March | Fair | | |
| ~mid-April 2027 | Stockholm Junior Water Prize, US state round (via WEF member association; 20-page paper) | Vihaan | open |

## ISEF forms

- Form 1 (Checklist for Adult Sponsor): sponsor signs.
- Form 1A (Student Checklist + Research Plan): use notes/ISEF_RESEARCH_PLAN.md;
  sign **before** the first prospective forecast is issued.
- Form 1B (Approval Form): student, parent, sponsor signatures, dated before
  the new work starts.
- Form 3 (Risk Assessment): **required.** The device workstream uses PAC powder
  (an acidic aluminium coagulant), a home-built 12 V electrical device and
  protist cultures. Designated Supervisor (school chemistry teacher, also named
  on Form 1) and Adult Sponsor both sign. Form 3 only — no SRC pre-review
  (notes/DEVICE_PROTOTYPE.md s6).
- **All four (1A, 1, 3, 1B) signed by Fri Sep 25, 2026**, before the first
  hands-on work on Mon Sep 28 (notes/LAB_PROTOCOL.md s1; DEVICE_PROTOTYPE.md s6).
- **CSEF (2026-10-04): Form 2A (Student Support Disclosure) is required for
  all projects.** Form 2B is required only for independent entries, not for
  this school entry. Forms 1, 1A, 1B are not uploaded to CSEF (the online form
  covers them) but are still needed if the project goes to ISEF.
- Not needed: Forms 4–7 — no human, vertebrate, PHBA, or continuation.
- Regulated Research Institution form: computational work done at home on
  public data. **Bench work (2026-10-04): all at Bi-Cultural Hebrew Academy
  (Stamford), not Westhill, under Direct Supervisor Meghana Fernandez (MS
  Microbiology, UCLA; adjunct professor, UConn).** Outside the student's own
  school, so file **Form 2C** to be safe (signed after experimentation).
  Form 3 filled 2026-10-04: `forms/Form 3.pdf`.

_2026-09-18: corrected. This block previously read "Form 3 (Risk Assessment) —
no hazards", which contradicted DEVICE_PROTOTYPE.md s6 and LAB_PROTOCOL.md s11;
Form 3 is required. The forms deadline is Fri Sep 25, not the Oct 5 shown in the
deliverables row below (now also corrected)._

## Deliverables and where they come from

| Deliverable | Source | Target date |
|---|---|---|
| Research plan | notes/ISEF_RESEARCH_PLAN.md | Sept 12 draft; final with sponsor |
| Abstract (250 words, five elements) | notes/ABSTRACT.md, written after the prospective readout | Jan |
| Paper (also serves SJWP) | notes/PAPER_OUTLINE.md rewrite → paper | Nov–Jan |
| Board / poster text | notes/BOARD.md | Jan |
| Judge Q&A sheet | notes/BOARD.md appendix | Jan |
| Project data book / log | git history of both repos + SCIENTIFIC_METHOD.md | continuous |
| Figures | figures/ in both repos; atlas screenshot | Jan |
| Device (Phase 11, MVP): order CCMP1332 + kaolin, PAC powder, magnetite pigment, **22** N52 blocks, square tube, ESP32 | notes/DEVICE_PROTOTYPE.md s3, s7; quote sheet notes/ORDER_LIST.md | **Sept 16-18** (was Sept 21, which is Yom Kippur; block count cut from 24 to 22 by Amendment A1) |
| Device: Forms 1/1A/1B/3 signed, Designated Supervisor (chemistry teacher) named | DEVICE_PROTOTYPE.md s6; LAB_PROTOCOL.md s1 | **Fri Sep 25** (was Oct 5; corrected 2026-09-18) |
| Device: week-1 chemistry + stock-preparation pilot; clay-only blank (gate) | SCIENTIFIC_METHOD.md Phase 11 | Oct 9 / Oct 23 |
| Device: three-arm jars, dose screen, 3 tank runs, board panel | DEVICE_PROTOTYPE.md s3, s9 | Nov 9 - Dec 18 |

## Outside contacts

| Who | For | Sent | Reply | Next nudge |
|---|---|---|---|---|
| CT DEEP (K. O'Brien-Clayton) + UConn (J. O'Donnell, T. Fake) | 2014 method/column change (corrected-to-raw ratio 0.4 -> 0.8 in 2014, corrected empty 2022-24); 2026 cruises to ERDDAP | 2026-09-14 (reply on June thread) | UConn replied 2026-09-17 (see the UConn row below). **DEEP answered 2026-09-22/23**: the 2014 step is a CTD instrument change (SeaBird to YSI EXO2 around 2009/2010), the lab is unchanged; use the lab data. M. Lyman (DEEP) is providing lab chl-a through July 2026. Label rebuilt on the lab scale (notes/LABEL_REBUILD_PREREG.md) | Done; watch for Lyman's lab chl-a file |
| UConn (J. O'Donnell) | same 2014 question (now answered by DEEP); presenting the work to his team | 2026-09-14 (on the joint DEEP/UConn thread) | **2026-09-17 — replied, interested in the work, offered a slot to present to his team once he is back from a conference** | Vihaan replied 2026-09-17 with availability (Mondays, Thursdays, Fridays); waiting on a time. Follow up if no time proposed by **Sep 25** |
| IEC (S. Wilder, cc E. Powers) | 2026 posting date / early share; IEC chlorophyll method stable through 2014? | 2026-09-14 | — | Sept 28 |
| CT DEEP (M. Becker, E. Marquis) | same 2014 question | not sent (drafts gone) | — | not needed: DEEP answered 2026-09-22/23 on the thread above |
| College counselor | sponsor referral | 2026-09-05 | — | Sept 12 |
| UConn LISICOS PI | fallback for buoy data questions | — | — | not needed for the 2014 question (DEEP answered 2026-09-22/23) |
| RIDEM Narragansett Bay program | training-bay confirmation | — | — | Oct 1 |

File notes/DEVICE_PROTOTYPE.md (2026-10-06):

<!-- notes/DEVICE_PROTOTYPE.md. v7-final, frozen for build 2026-09-15 after two build/review loops
(builder agent; reviewers 1-3 on v1-v3, scientist verification of v4, reviewers 4-6 on v5-v7; all in
notes/device_reviews/ and notes/DEVICE_VERIFICATION.md). Design freeze for the bench program is Fri Nov 6, 2026
(Nov 13 if the culture arrives after Oct 8). Pre-registration: SCIENTIFIC_METHOD.md Phase 11, amended 2026-09-15
to match this version (bands unchanged). Companion research: notes/CLAY_RETRIEVAL_RESEARCH.md,
notes/CLAY_FLOCCULATION_RESEARCH.md, notes/AERATION_RESEARCH.md. -->

# Ledger-triggered magnetic clay flocculation with magnetic retrieval: design v8 (v7-final + Amendment A1)

Source keys: [RET] = notes/CLAY_RETRIEVAL_RESEARCH.md, [CLAY] = notes/CLAY_FLOCCULATION_RESEARCH.md, [AER] = notes/AERATION_RESEARCH.md, [PROT] = hab-bloom-predictor-narragansett/notes/PROSPECTIVE_PROTOCOL.md s1, s5, s7 plus `LEDGER_COLS` in `src/deploy/prospective_forecast.py`, [SM11] = notes/SCIENTIFIC_METHOD.md Phase 11 (lines 536-608), [R1]-[R6] = review1-6.md, [V] = verification.md, **[A]** = my assumption or calculation. Prices are reviewer-verified where tagged, otherwise **[A]**.

## 0. Changelog from v7 (freeze audit) [R6]

| Edit | What changed |
|---|---|
| C1 | s10 item 8 now starts at "Forms 1/1A/1B/3 signed by Oct 5;" so the gate line is replaced whole, not duplicated; item 9 inserts reviewer 5's three qualifications after `not "no study")`. |
| C2 | s10 item 1 "to" text adds the second-loop clause (reviews 4-6 took v4 to v7); DEVICE_PROTOTYPE.md header must change from "Frozen 2026-09-15 as v4" when v7-final is written in. |
| C3 | H11c "to" text gets a pass criterion; s10 preamble now says which bands move (none for H11a/H11b recovery; H11b plain becomes a description; H11c changes method); item 6 keeps the Yu 2016 rationale; items 3 and 5 use double quotes; H11a "(product basis; stock route S or D per the Oct 30 amendment)" and "n = 3 batches"; H11b "in the winning route's blank". |
| C4 | Release physics corrected: no steel in the frame, so no 25 kg press; inner stacks < 1 kgf on the rod, end stacks 3-5 kgf against their outer side wall (~13 kgf neighbour repulsion), that wall PTFE-lined too; tubes captured in through-slots in the wooden end rails, end-blocks screwed not glued, every block epoxied to a carrier strip; contingency is a rebuilt 8-tube frame at 30 mm centres (240 mm), blocks ordered Oct 23 for Oct 27; s6 magnet line corrected. |
| C5 | Two loose N52 blocks (pull test, settling) added; BOM $796 / $629 / $565 / $513. |
| C6 | Blanks: fraction (iii) at T111 and 07:30 the next school morning, drain and floor rinse after the second siphon; blank #2 moved to Thu Oct 15 (paste D Wed Oct 14) so all three blanks settle 17 h; 7a rewritten accordingly; s10 item 8 "to" text carries D (Oct 15), the one departure from the quoted text, forced by the move. |
| C7 | DRV5055A4 spot map at 10, 15, 20, 30 mm (saturates above ~170 mT). |
| C8 | Column cycle ~4.7 min, two cycles 9.3 of 10 min; aliquot line "56-75 mg magnetite at 37.5-50 wt%"; run days 14:15 setup to 17:30 under the agreement. |

<details><summary>Earlier changelogs (collapsed)</summary>

v6 to v7 [R5]: runs off Mondays with clock times and an after-hours agreement; culture ordered Sep 16-18 with a written ship date; recovery gate inverted per route; pull-test aliquots and pad-height standards; release mechanics; draws and siphons specified; culture water pasteurised; statistics (t-interval, bracketed D90, plain n = 1, index +/-20%, Lin's CCC); controller-timed, student-mixed; $8 blocks; s10 as a diff; overclaims; 7a.
v5 to v6 [R4]: within-tank resuspension index; route blanks S and D plus plain; dry blends pasted T-24 h; carboy B pilot; SEN0189/DO logging, kits, ImageJ, regrowth cut; fraction (iii) floor; ICP first draw; Version A/B arithmetic.
v4 to v5 [V]: stock-route pilot; floor measurements and four-fraction attribution; pull-test drift; partner ICP Al; field Versions A/B; board sentences; wasted-dose arithmetic; open issues.
v3 to v4 [R3]: 30-40 mm pull test; pigment blend; square tube, skids, per-pass release; DRV5055A4; pad workup; MVP; board text, H11a-c, gates.
v2 to v3 [R2]: settle-raster-column; matched jars; logistic D90; NaOH titration; PAC solids basis; controller bands dropped; counting budget.
v1 to v2 [R1]: sleeved rods; Sedgewick-Rafter and extracted Chl; NaOH; magnetite Plan B; G stated; three arms; ledger keys.

</details>

## A1. Amendment A1, 2026-09-16: simulation-optimised settings (governs over sections 1-12 where they conflict)

Applied before any bench work, from the optimisation sweep in notes/DEVICE_SIMULATION.md s4 (1,728 flocculation settings, 12 rake layouts, 36 speed/skid/magnetite combinations). Hypothesis bands H11a-c do not move; SCIENTIFIC_METHOD.md Phase 11 carries the matching dated amendment.

| Setting | v7-final | A1 | Basis (simulation) |
|---|---|---|---|
| Magnetite in the dry blend | 37.5% (15 : 18.5 : 6.5 per 40 g) | **20%: 8 g magnetite : 25.3 g EPK kaolin : 6.7 g PAC powder per 40 g** (PAC stays 5:1 on mineral solids) | capture of settled flocs >= 99% down to 10% magnetite at <= 2 cm/s and <= 6 mm skid; 20% keeps margin for flocs that incorporate little magnetite. Iron added ~29 mg/L instead of 54; aluminium unchanged at ~5 mg/L |
| Slow mix | 30 rpm paddle, G ~30, 15 min | **G ~60 for 10 min**: tank paddle motor 48-50 rpm (G scales as rpm^1.5); jar rig motors ~95-100 rpm | same settled fraction (95% vs 96%, pre-aggregated stock) in less time. Risk: breakup at G 60 is represented only by a size cap |
| Settle | 15 min | **10 min** | same settled fraction at G 60 |
| Magnet stacks | 6 (24 blocks) | **5 (20 blocks)** at 33 mm centres; frame span 163.75 mm | 4 is the model minimum; 5 keeps the per-pass pad <= 2.5 mm on 160 cm2 of pole face at 0.2 g/L |
| Floor passes | 3, lanes at 11 / 41 / 11 mm | **2: pass 1 with the outer tube against long wall A (edge 0.5 mm), pass 2 against long wall B (edge 85.75 mm)** | 100% of settled flocs with 4-7 stacks; the v7 third pass repeated lane A |
| Column passes | 2 cycles | 1 cycle | not modelled; kept as a straggler sweep |
| Rake speed | 1 cm/s | **2 cm/s** | capture unchanged to 8 cm/s; capped at 2 because resuspension is unmodelled |
| Skid | 3 mm | 3 mm | 10 mm loses flocs at speed |
| Dose screen (H11c MVP) | 0.05, 0.1, 0.2 g/L | **0.05, 0.1, 0.2, 0.4 g/L** (12 jars) | chemistry dominates; 0.4 is the robust dose if the stock flocculates poorly |
| Recovery-gate contingency | 8-tube frame at 30 mm | **diagnose first**: floc photo at T11 and a 10 mL column count at T20. Loss in the column: chemistry (dose 0.4 or other stock route). Loss on the floor: add a centre pass. Loss in the tube rinse: slow the withdrawal | the 8-tube frame needs 254 mm on a 250 mm floor, and magnet reach is not the failure mode |

**Run clock under A1** (T = minutes from dosing): T0-T1 drill; **T1-T11 paddle at G ~60**; **T11-T21 settle**, T20 count, floor sample, DO; **T21-T29 two floor passes** at 2 cm/s with release after each (~3.6 min per cycle: ~37 s travel, ~3 min lift, release, rinse, reinsert); **T29-T33 one column cycle**; T33 count and floor sample; **T93** floor sample and DO (1 h after raster). 5 h and 24 h reads unchanged. Resuspension index = T33 count / T20 count. Blanks take fraction (iii) at T93 and next school morning.
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

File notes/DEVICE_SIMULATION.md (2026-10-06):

# Device simulation: magnet field, floc growth, floor-raster capture

Written 2026-09-16, before any bench work. Scripts in `src/sim/`, figures in `figures/sim/`, CSVs in `data/sim/` (gitignored, regenerable). Parameters are the v7-final design in notes/DEVICE_PROTOTYPE.md s3. Base conda env; one added dependency, `magpylib` 5.2.3.
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

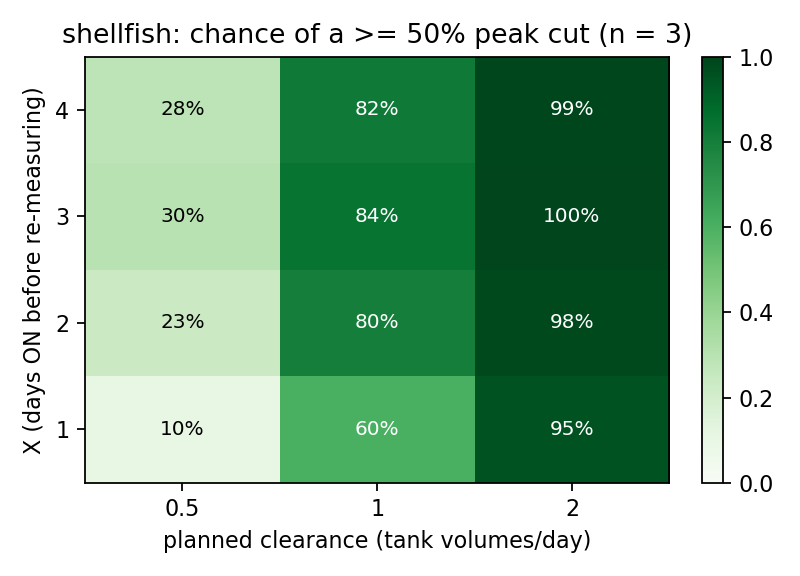
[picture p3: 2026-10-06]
figures/sim/fig_method_design_shellfish.png

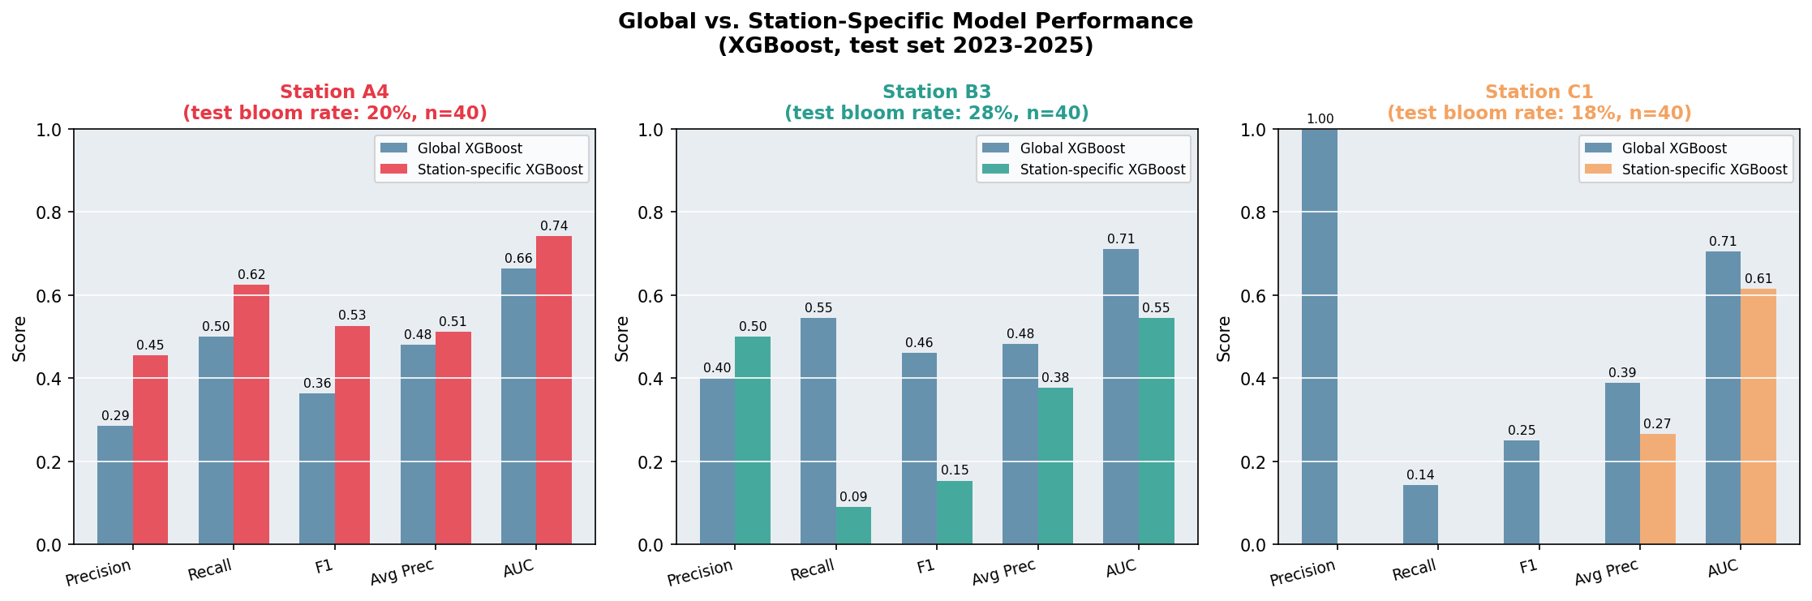
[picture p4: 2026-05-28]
figures/fig_station_specific.png

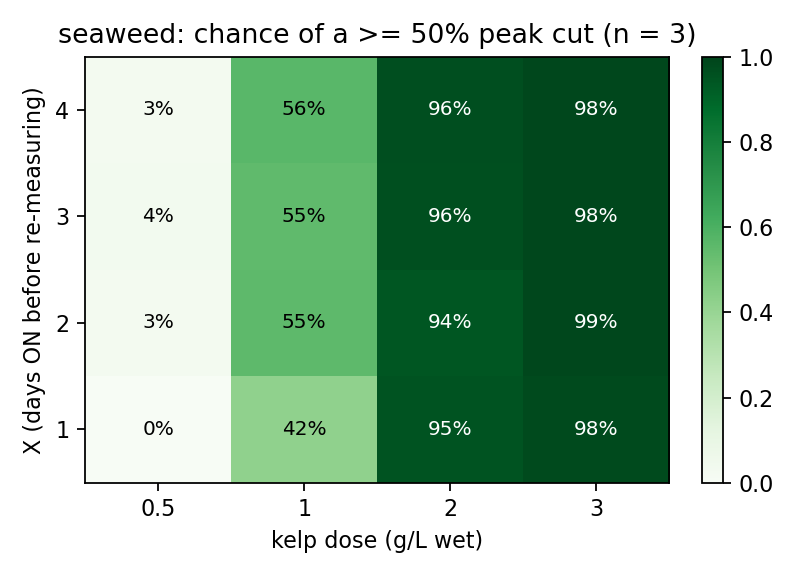
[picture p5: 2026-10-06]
figures/sim/fig_method_design_seaweed.png

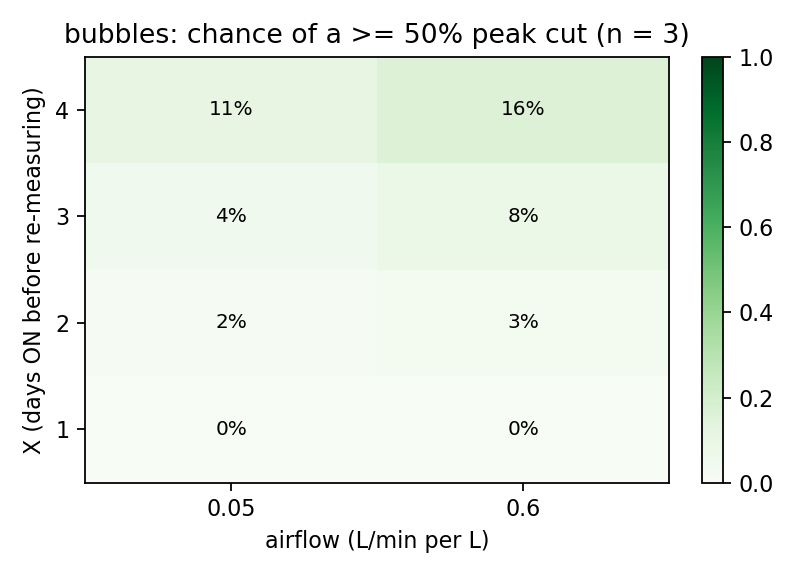
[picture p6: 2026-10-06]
figures/sim/fig_method_design_bubbles.png

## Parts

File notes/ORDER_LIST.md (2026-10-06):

# Order list — bench build, design v8

Shopping worksheet for the materials in `notes/LAB_PROTOCOL.md` sections 2, 3 and 10: one row per orderable item, with the budget line it belongs to and where to go looking.
**No price in this file is a live quote.** The "Budgeted $" column is only the section 10 planning figure; every "Actual $" cell is blank on purpose — fill it in from your own browser today, because vendors, stock and shipping change.

Budget groups (section 10): **A** magnets 176 · **B** rake hardware 58 · **C** vessels 85 · **D** clay + PAC 47 · **E** electronics 85 · **F** chamber 60 · **G** GF/F 40 · **H** culture/consumables 149.

## Items

| Item | Spec | Qty | Budgeted $ | Where to look | Actual $ | Notes |
|---|---|---|---|---|---|---|
| N52 block magnets | 40 x 20 x 10 mm, nickel-plated, axially magnetised through the 10 mm | 22 | A: 176 total (~8 ea) | Magnet houses: K&J Magnetics (kjmagnetics.com), Applied Magnets / magnet4less.com, CMS Magnetics, Apex Magnets | | **Quote this first** — swing item. 20 in stacks + 1 pull test + 1 settling. Ask about bulk price at 22 and shipping surcharge. |
| Square acrylic tube | 1-1/4 in square, 1/8 in wall, ~4 ft | 1 | B: 58 group | Plastics distributors: US Plastic Corp (usplastic.com), TAP Plastics, McMaster-Carr (mcmaster.com), Delvie's Plastics | | Cut to 5 tube lengths + end caps. |
| Nylon rod | 8 mm (or 5/16 in) diameter, ~1 m | 1 | B: 58 group | McMaster-Carr, US Plastic Corp | | Through removable top cap into nylon end-block. |
| Wooden end rails, skids, handles | Hardwood strip for slotted rails at 33 mm centres; 3 mm skid stock; 2 handles; wood screws | 1 set | B: 58 group | Home Depot, Lowe's, local lumber yard; Rockler for hardwood strip | | Screwed, not glued. Add PTFE plumber's tape (hardware store) here. |
| Release tray | ~30 x 25 cm shallow plastic/stainless tray + wash bottle | 1 | B: 58 group | Restaurant supply (WebstaurantStore), US Plastic Corp, Home Depot (boot tray); wash bottle from Flinn Scientific or Carolina Biological | | |
| Aquarium | 10 gal glass, standard 50 x 25 cm footprint | 1 | C: 85 group | Aquarium retailers: Petco, PetSmart, local fish store; Amazon | | Petco/PetSmart run dollar-per-gallon sales — check before paying list. |
| Jars | 2 L glass, wide mouth, straight sided | 6 | C: 85 group | Ball / Anchor Hocking half-gallon jars at Walmart, Target, ACE; lab-grade from Carolina Biological or Qorpak | | **Borrow candidate** — ask the chem teacher for 6 matching beakers/jars first. |
| Carboys | 20 L (5 gal) HDPE or glass, with cap | 2 | C: 85 group | Homebrew suppliers: Northern Brewer (northernbrewer.com), MoreBeer, Adventures in Homebrewing; US Plastic Corp | | Must autoclave/pasteurise-tolerant for f/2. |
| Filter bag | 5 um felt/polyester, standard ring top | 1-2 | C: 85 group | Homebrew and pool suppliers: Northern Brewer, Duda Diesel, US Plastic Corp, McMaster-Carr | | Gravity filtration of seawater diluent. |
| Sample bottles | 125-250 mL HDPE, wide mouth, with caps | ~24 | C: 85 group | Fisher Scientific, Cole-Parmer, US Plastic Corp, Qorpak | | Separate from the trace-metal bottles below. |
| Magnetite pigment | Black iron oxide (Fe3O4) powder, 1 lb | 1 | D: 47 group | Ceramics suppliers: Sheffield Pottery (sheffield-pottery.com), The Ceramic Shop, Axner, Laguna Clay. Pigment houses: The Earth Pigments Company, Kremer Pigmente | | Confirm it is magnetite (Fe3O4), not hematite (Fe2O3) — a magnet on the bag settles it. |
| EPK kaolin | Edgar Plastic Kaolin, 5 lb | 1 | D: 47 group | Sheffield Pottery, The Ceramic Shop, Axner, Big Ceramic Store, Laguna Clay | | Cheapest item to over-buy; 5 lb is plenty. |
| PAC powder | Polyaluminium chloride, 28-30% Al2O3, 1 kg | 1 | D: 47 group | Pool/water-treatment suppliers: Duda Diesel (dudadiesel.com), ChemWorld, Pool supply houses (Leslie's — ask for PAC clarifier, powder not liquid); lab grade from Sigma-Aldrich | | **Get the COA or spec sheet for %Al2O3** — the 28-30% assumption sets the dose. |
| ESP32 dev board | Any ESP32-WROOM-32 dev kit, USB | 1 | E: 85 group | Adafruit, SparkFun, DigiKey, Mouser, Amazon | | |
| Relay module | 2-channel, 5 V logic, opto-isolated | 1 | E: 85 group | Amazon, Adafruit, SparkFun | | Switches pump and paddle. |
| microSD card module | SPI breakout + 8-32 GB card | 1 | E: 85 group | Adafruit, SparkFun, Amazon | | Keep the card away from the magnets. |
| Peristaltic pump | 12 V DC, ~60 mL/min, silicone tubing head | 1 | E: 85 group | Adafruit, Amazon (Kamoer / Gikfun), Cole-Parmer (Masterflex, higher end) | | Note tubing ID so the siphon tubing matches. |
| Gearmotors, jar rig | 12 V DC, ~100 rpm, identical units | 3 | E: 85 group | ServoCity (servocity.com), Pololu (pololu.com), Amazon (Greartisan) | | Must be three of the same part number — G is matched across jars. |
| Gearmotor, tank paddle | 12 V DC, ~50 rpm | 1 | E: 85 group | ServoCity, Pololu, Amazon (Greartisan) | | Drives the 15 cm paddle at 48-50 rpm, G ~60. |
| Power supply | 12 V, 5 A, fused, barrel or screw terminal | 1 | E: 85 group | Mean Well via DigiKey or Mouser; Adafruit; Amazon | | **Borrow candidate** — a lab bench supply works. Behind a GFCI either way. |
| Hall sensor | DRV5055A4 (linear, ±21 mT) | 2-3 | E: 85 group | DigiKey, Mouser, Texas Instruments direct; Pololu sells a carrier board | | Buy spares; they are cents each and easy to cook. |
| Sedgewick-Rafter chamber | 1 mL, ruled, with cover glass | 1 | F: 60 | Wildco (wildco.com), Aquatic Research Instruments, Pyser Instruments, Fisher Scientific, Cole-Parmer | | **Borrow candidate #1** — ask UConn/DEEP partner before ordering (already on the Sep 22 email list). |
| GF/F filters | Whatman GF/F, 47 mm, 0.7 um nominal, box of 100 | 1 | G: 40 | Cytiva Whatman via Fisher Scientific, Cole-Parmer, Sigma-Aldrich, MilliporeSigma | | Generic borosilicate 0.7 um is acceptable if Whatman is backordered — record the brand. |
| f/2 medium | Guillard's f/2 (+Si for diatoms), enough for ~24 L | 1 | H: 149 group | NCMA at Bigelow (ncma.bigelow.org — sells media with cultures), Florida Aqua Farms (florida-aqua-farms.com, Proline f/2), Carolina Biological | | **Borrow candidate #2** — partner lab may make it up for free. **Must include silicate** for *Skeletonema*. |
| Culture LED | Cool white, ~100-150 umol/m2/s at jar face, with timer | 1 | H: 149 group | Home Depot / Lowe's LED shop light; Amazon; aquarium retailers (Petco, Bulk Reef Supply) | | **Borrow candidate #3** — a plant/aquarium light from the bio classroom. Add a mechanical outlet timer. |
| Lugol's iodine | Acid or neutral Lugol's, 100 mL | 1 | H: 149 group | Carolina Biological, Ward's Science, Flinn Scientific, Florida Aqua Farms | | Preservative for counts. Check school policy on iodine storage. |
| pH pen | ±0.1 pH, with calibration buffers | 1 | H: 149 group | Apera Instruments, Hanna Instruments (hannainst.com), Oakton via Cole-Parmer; hydroponics and pool shops | | Buy pH 4 / 7 / 10 buffer sachets with it. |
| Syringe filters | 0.45 um, 25 mm, PES or nylon, pack of 50-100 | 1 | H: 149 group | Fisher Scientific, Cole-Parmer, Restek, Sigma-Aldrich, Amazon | | For the ICP aluminium samples. |
| Trace-metal HDPE bottles | 60-125 mL, acid-cleaned / trace-metal grade | 6-8 | H: 149 group | Fisher Scientific (Nalgene), Environmental Express, Qorpak, Cole-Parmer | | Ask the ICP lab which bottle and preservative **they** want before buying. |
| Acetone | 90% or reagent grade, 500 mL - 1 L | 1 | H: 149 group | School chemistry stockroom first; Flinn Scientific, Carolina Biological; hardware-store acetone (Home Depot) diluted to 90% | | Chlorophyll extraction. Flammable — hood and teacher supervision. |
| PPE | Nitrile gloves, splash goggles, N95/P2 dust masks, lab coat or apron | 1 set | H: 149 group | ULINE, Grainger, Flinn Scientific, Home Depot | | Dust masks are for weighing PAC and magnetite in the hood. |
| Siphon tubing | 6 mm ID silicone or vinyl, ~5 m | 1 | H: 149 group | Homebrew suppliers (Northern Brewer), US Plastic Corp, hardware store | | Match ID to the peristaltic pump head. |
| Syringes | 10 mL, 50 mL, 60 mL luer, several each | ~10 | H: 149 group | Amazon, Cole-Parmer, Carolina Biological, Tractor Supply (farm/vet syringes) | | 60 mL luer must mate with the 0.45 um filters. |
| *Skeletonema marinoi* culture | NCMA **CCMP1332**, live starter culture | 1 | H: 149 group | NCMA at Bigelow Laboratory — ncma.bigelow.org | | **Order first, everything else waits on it.** See "Before you order". |
| ICP aluminium analysis (conditional) | 5 samples, dissolved Al by ICP | 5 | conditional 125-150 | Only if the partner lab cannot run it: commercial environmental labs — Eurofins, Pace Analytical, ALS, or a Connecticut lab such as Phoenix Environmental / Con-Test | | Not in the 700. Ask the partner lab (Sep 22 email) before you price this. |
| **TOTAL** | | | **700 buy everything / 533 with five borrows** | | **______** | Your sum here. Add ~125-150 if ICP goes commercial. |

## Swing items

**The magnets decide the budget.** 22 N52 blocks at the budgeted $8 each is $176 — a quarter of the whole $700. A real quote 30% either way moves the total more than any other line, so get the magnet price in writing before you commit to anything else. If the quote comes back high, options are: fewer spares (20 blocks, no settling spare), unplated blocks, or a different supplier's equivalent grade.

**The five borrows that take the total from $700 to $533** — ask the school and the partner lab for these *first*, before ordering:

| Borrow | Ask who |
|---|---|
| Sedgewick-Rafter chamber | UConn / CT DEEP partner lab (already on the Sep 22 email) |
| 2 L jars (6, matching) | School chemistry teacher — beakers or jars |
| f/2 medium | Partner lab, or school bio department |
| Culture light | School biology classroom (plant/growth light) |
| 12 V 5 A power supply | School physics/robotics bench supply |

Anything you cannot borrow, buy — but log which five you got, because that is the difference between the two totals.

## Before you order

- [ ] **Order the CCMP1332 culture first.** NCMA ships live cultures on **Wednesdays** with at least a **two-week lead**. Order date drives the entire calendar; earliest arrival is Thu Oct 8, which sets the Oct 9 gate, the Oct 23 blank gate and everything after. Get the ship date **in writing**.
- [ ] Confirm someone will be at the delivery address on the arrival Thursday — a live culture cannot sit on a porch.
- [ ] **ISEF Forms 1A, 1, 3 and 1B signed by Fri Sep 25** (Adult Sponsor; Designated Supervisor = school chemistry teacher on Forms 1 and 3), plus the signed after-hours agreement. **No hands-on work before those signatures.** Ordering and receiving materials is not hands-on work, so the culture order does not wait on the forms — but the Oct 5-9 calibrations do.
- [ ] Quote the N52 blocks before placing any other order (see Swing items).
- [ ] Get the PAC %Al2O3 spec sheet before buying — the 28-30% figure sets the blend recipe.
- [ ] Ask the ICP lab for their preferred bottle and preservative before buying trace-metal bottles.
- [ ] Check the school stockroom for acetone, Lugol's, gloves, goggles and dust masks before adding them to a cart.
- [ ] Ship-to address: confirm whether chemicals (PAC, acetone) can go to the school or must go home.
- [ ] Book the shared instruments by **Sep 22**: fume hood, water bath, spectrophotometer, 0.001 g balance, microscope, drying oven.

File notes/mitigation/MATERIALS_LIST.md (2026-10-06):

# Materials list, by experiment

Written 2026-09-26 from `EXECUTION_PLAN.md` §6-8 and the method docs. **Updated 2026-09-28:**
- every item now says what it does and why we need it;
- the make-or-break fixes (`EXECUTION_PLAN.md` §11) are added;
- the electronics match the Arduino alerter actually being built.

**Updated 2026-10-01:** the plan is now **aeration and peroxide only** (the device must run fully
autonomously; `EXECUTION_PLAN.md`, "Plan change 2026-10-01"). Kelp, shellfish and curcumin/ethanol
items are removed (listed at the end as dropped). Added: *Micromonas pusilla* and *Nannochloropsis*
cultures for the cell-size panel, a hemocytometer, the loop-run air supply, and the peristaltic pump
and 3% H₂O₂ reservoir for the peroxide loop run.

Prices are estimates. **Borrow first:** ask the sponsor for the microscope, scale, glassware and
pH/DO meters before buying.

Current plan:
- two **screens** (small flasks, days) on a cell-size species panel;
- two **full loop runs** (tanks, weeks): **aeration** and **peroxide**.

## 0. Shared kit (buy once, used by every experiment)

**Electronics: the alerter** (details and links in `hardware/alerter_uno/README.md`)

| Item | Qty | Approx. | What it does | Why we need it |
|---|---|---|---|---|
| Arduino Uno + breadboard, LEDs, buzzer, wires | 1 (have; a 2nd Uno planned) | $0-25 | The "brain": runs the ON/OFF rules, lights the status LEDs, beeps | It *is* the control loop: it decides when a treatment switches on and off, the same way every time |
| Relay + PN2222A transistor + 1N4007 diode | 1 (have) | $0 | An electrically controlled switch; the transistor lets the Arduino drive it, and the diode protects the Arduino from the relay's voltage kick | Lets a 5 V Arduino switch a 12 V pump (air or dosing) on and off automatically |
| 12 V pump + tubing + 12 V 2 A adapter | 2 pumps / 1 kit / 1 (ordered) | $27 | A diaphragm pump: moves air or water when the relay closes | Runs aeration and circulates tank water (e.g. through the sensor); it can't meter microdoses |
| **Peristaltic dosing pump** (12 V, with silicone tubing) | 1 (+1 spare) | $15-25 each | Pushes a measured volume each time it runs; calibrated by weighing what it delivers | **Now needed for the peroxide loop run (2026-10-01):** doses 3% H₂O₂ from the reservoir in 0.8 mg/L pulses (0.27 mL per 10 L tank) |
| DS18B20 waterproof temperature sensor + 4.7 kΩ resistor | 1+ (ordered) | $10 | Measures water temperature | Temperature is a model input, and a safety check: pump heat must not warm the tank more than 2 °C |
| pH module (probe + board) + pH 6.86 / 9.18 buffer powder | 1 / 12-pack (ordered) | $25 | Measures how acidic or basic the water is; the buffers calibrate it | Bubbling (CO₂) and percarbonate change pH, and the loop must stop above pH 9.0 or outside 7.6-8.6 |
| **DIY fluorometer:** TSL2591 light sensor + blue LED + red gel filter + 3D-printed dark box + cuvettes | 1 set (ordered; box printed at school) | $45 | The blue LED makes chlorophyll glow red; the gel blocks the blue; the sensor measures the red glow in the dark box | **The main measurement.** Chlorophyll glow is how the loop "sees" the algae every day, without a lab machine; it is also the main measure for the ~2 µm algae |

**Water, algae and counting**

| Item | Qty | Approx. | What it does | Why we need it |
|---|---|---|---|---|
| Artificial sea salt + refractometer | 1 bag / 1 | $45 | Salt makes seawater; the refractometer measures salinity | The tanks copy the western Sound at salinity 27.5 (WATER_RECIPE.md); evaporation (worse with bubbling) raises it, so we check and top up |
| f/2 medium (make f/4 by halving) | 1 kit | $30 | Algae "fertilizer": nitrogen, phosphorus, vitamins, trace metals | Grows the cultures, and the nutrient pulse on day 21 is what starts the bloom |
| **Cultures from NCMA:** *Skeletonema* (lead diatom), *Thalassiosira weissflogii*, *Phaeodactylum* (backup), dinoflagellate *Akashiwo* / *P. triestinum*, *P. micans*, ***Micromonas pusilla*** | 5-6 strains | $250-400 | Living, non-toxic stand-ins for bloom algae, from ~2 µm to ~50 µm | The "bloom" we try to stop, and the cell-size panel. *Micromonas* (~2 µm) was wiped out by peroxide in Randhawa et al. 2012; *Skeletonema* is the dominant diatom of Long Island Sound blooms |
| **Live *Nannochloropsis*** (reef-aquarium phytoplankton, sold as coral and rotifer food) | 1 bottle | $15-25 | A harmless 2-3 µm alga, bought live | Second small-celled alga for the size panel; its peroxide sensitivity is untested in our papers, so it is a real test. Check it under the microscope and keep a clean sub-culture (NCMA *Nannochloropsis* as backup) |
| Backup culture flasks | 2 per strain | (from the flasks below) | Spare copies of every culture | If a culture crashes or gets contaminated, we restart instead of losing the run |
| Sedgewick-Rafter counting chamber + transfer pipettes | 1 / 200 | $30 | A slide with a 1 mL grid for counting cells under a microscope | Cell counts are the ground truth for the larger cells: the fluorometer measures glow, which treatments can distort |
| **Hemocytometer** (Neubauer) + cover slips | 1 | $20 | A fine-grid counting slide for very small cells at 400× | Counts the ~2 µm *Micromonas* and *Nannochloropsis*, which are too small for the Sedgewick-Rafter slide; hard at school, so it checks the fluorometer rather than replacing it |
| Microscope with 40× objective (400×) (borrow) + phone adapter | 1 / 1 | $0-15 | Magnifies the cells; the adapter lets a phone photograph them | Counting; photos are counted later in ImageJ, which cuts the daily counting time |
| Scale, 0.01 g (borrow if possible) | 1 | $20 | Weighs small amounts | Percarbonate, sodium carbonate, salt, nutrient salts |
| Adjustable micropipettes (10-100 µL and 100-1000 µL) + tips | 2 | $50 | Measure tiny volumes exactly | Flask doses of 160-1280 µL of the peroxide working solutions (PROCEDURES P6) |
| LED grow lights + outlet timers | 2 | $60 | Light on a fixed 16:8 or 12:12 day | Algae need steady light to grow the same in every tank |
| GFCI power strip | 1 | $20 | Cuts power instantly if current leaks to water | Safety: pumps and lights near water |
| *Artemia* (brine shrimp) eggs + hatching cone | 1 | $15 | Tiny animals hatched on demand | The non-target check: if a treatment kills brine shrimp, it isn't safe |
| DO (dissolved oxygen) test kit | 1 | $30 | Measures oxygen in the water | Safety: dying algae use oxygen at night; the loop stops below 4 mg/L. Also the dawn-DO test for aeration |
| **Chlorophyll reference**: 90% acetone + borrowed spectrophotometer (or a borrowed calibrated fluorometer) | 1 | $0-20 | Measures true chlorophyll in µg/L | Calibrates the DIY fluorometer (`chlk`) so C_ok and the floor are in µg/L (PROCEDURES P3) |
| Goggles, nitrile gloves, lab notebook, labels | 1 set | $20 | Protection and records | Required for chemicals, and the notebook is the official record for ISEF |

**Untreated and pilot tanks** (one set per loop culture; shared if both screens pick the same culture)

| Item | Qty | Approx. | What it does | Why we need it |
|---|---|---|---|---|
| Arm A tanks (untreated) | 3 per culture (6) | $80 | Algae bloom with no treatment | The baseline: the treatment's effect (peak cut, or days held below `C_ok` for aeration) is measured against these |
| **Pilot bloom tanks** | 2 per culture (4) | $50 | Get nutrients early, during warm-up, with no treatment | Prove the culture actually blooms in our tanks before the real run, and give the expected peak that arm C's start and `C_ok` are set from. Reused as spares afterwards |

## 1. Aeration (screen, 4 days + full loop run #1)

**Screen (4 days):**

| Item | Qty | Approx. | What it does | Why we need it |
|---|---|---|---|---|
| 1 L flasks (500 mL culture each): still, low, high, **gentle** × 4 species (*Micromonas*, *Nannochloropsis*, *Skeletonema*, dinoflagellate) × n = 3 | 48 | $95 | Holds each culture | Copies the Sung & Gobler setup so our result is comparable; the panel shows which cell sizes aeration slows |
| Aquarium air pumps + gang manifold + needle valves + tubing | 2 | $40 | Pumps air; the valves set each flask's flow | Airflow is the "dose", and every flask in an arm must get the same flow |
| Air stones | 36 | $20 | Break the air into bubbles at the bottom | What the paper used to make the bubbles |
| Flow meter (rotameter, 0-500 mL/min) | 1 | $20 | Measures airflow | Sets 25 and 300 mL/min exactly (0.05 and 0.6 L/min per litre) |

The **gentle-bubbling control** (a few bubbles per second) adds CO₂ without stirring. Bubbling
supplies CO₂, which *helps* growth and can hide the stress effect; this arm separates the two.

**Loop run:**

| Item | Qty | Approx. | What it does | Why we need it |
|---|---|---|---|---|
| Tanks, 4-10 L (arms B, C, D) | 9 | $80 | The treated tanks | Arm B = forecast loop, C = reactive start, D = false alarm |
| Air pumps for the treated tanks (each tank's air switched by the relay), airline, check valves, air stones | 9 outlets | $60 | Bubbles each tank at 0.6 L/min per litre when the loop says ON | The treatment itself; check valves stop tank water siphoning back into the pump when it switches OFF |

The aeration outcome (days below `C_ok`, hours ON, ON episodes) comes from the alerter's CSV log and
the daily fluorometer readings; it needs no extra kit.

## 2. Peroxide (screen, 72 h + full loop run #2)

**Screen (72 h, *Artemia* to 96 h):**

| Item | Qty | Approx. | What it does | Why we need it |
|---|---|---|---|---|
| 250 mL flasks: 0, 0.8, 1.6, 3.2, 6.4 mg/L × 5 species, + 3-pulse 0.8 arm × 2 small algae, + percarbonate × 3 species, + Na₂CO₃, × n = 3 | 93 | $125 | Test cultures | A dose ladder from ~2 µm to ~50 µm cells tests the "only kills small cells" idea (H5) |
| Drugstore 3% H₂O₂ | 2 bottles | $6 | Liquid peroxide | **Main dosing method**: diluted to 0.1% for flasks (160 µL per 200 mL = 0.8 mg/L) and pumped in tanks (0.27 mL of 3% per 10 L) |
| Sodium percarbonate, pure (oxygen-bleach powder, no fragrance or surfactant) | 1 small tub | $10 | Dissolves into hydrogen peroxide plus washing soda | The active ingredient of registered pond algaecides; tested in the screen only, as the "real-world product" version at the same peroxide dose |
| **Low-range peroxide test kit** (steps below 1 mg/L) | 1 | $30-60 | Measures peroxide at low levels | Strips can't tell 0.8 from 0.5 mg/L; this confirms the dose and the ≤ 0.5 mg/L re-dose rule |
| H₂O₂ test strips, 0.5-25 mg/L | 1 pack | $20 | Rough peroxide reading | The fast check for the 2.8 mg/L safety cutoff |
| **5 µm syringe filters + syringes** | 60 + 5 | $30 | Let only small cells through | Size-fractionated chlorophyll in the mixed loop tanks: small vs large cells |
| Washing soda (Na₂CO₃) | 1 | $5 | The carbonate part of percarbonate, without the peroxide | Control: shows whether the effect is peroxide or just the carbonate and pH rise |

**Loop run:**

| Item | Qty | Approx. | What it does | Why we need it |
|---|---|---|---|---|
| Tanks, 4-10 L (arms B, C, D) | 9 | $80 | The treated tanks | Arm B = forecast loop, C = reactive start, D = false alarm |
| 3% H₂O₂ reservoir bottle (dark, capped) feeding the peristaltic pump | 1 | $5 | Holds the peroxide the pump draws from | Stable for weeks, so the device runs with at most a refill; strength checked weekly with the low-range kit |

**Dosing module, inline dilution (added 2026-10-03; `hardware/alerter_uno/README.md` stage 9).** The
bench module doses the 0.1% working dilution; the 7% stock is for the field design (one bottle to
show and test the parts with, not dosed into tanks).

| Item | Qty | Approx. | What it does | Why we need it |
|---|---|---|---|---|
| 7% H₂O₂, plain (no surfactant, fragrance or stabiliser blend) | 1 L | $15 | The field-design stock | 2.4× less volume than 3% for a 2-week service interval, and below the ~8% corrosive line; surfactants would harm non-targets |
| Opaque HDPE jug with vented cap | 1 | $10 | Holds the stock in the dark | Light and heat break peroxide down; HDPE resists it; the vent stops gas building up |
| 12 V circulation pump (bench: small aquarium pump; field: 10-20 L/min) | 1 | $15 | Draws water in and pushes it through the mixing hose | Dilutes the peroxide inline so there is no concentrated jet at the outlet |
| Intake screen (2-5 mm mesh) | 1 | $3 | Covers the circulation pump's intake | Keeps debris and animals out of the pump and the flow switch |
| Check valve (peroxide-compatible) | 1 | $4 | One-way valve between the dosing pump and the tee | Stops water pushing back into the dosing line or siphoning stock |
| Tee + 1 m mixing hose (or an inline static mixer) | 1 | $6 | Joins the dose into the water stream and mixes it | Blends the dose before the outlet (~1:150 in the field) |
| Flow switch (inline, closes on flow) | 1 | $8 | Tells the Uno that water is moving (D8) | The no-flow interlock: never dose into a dead line |
| Float switch | 1 | $4 | Closes when the jug runs low (D4) | Prints `REFILL` so the service visit is not missed |
| 2-channel 5 V relay module | 1 | $8 | Switches the dosing pump (D10) and the circulation pump (D12) | Two pumps, two independent switches |
| Peroxide-compatible tubing (silicone in the pump head; PE or PVC elsewhere) | 2 m | $6 | Carries the stock and the mix | Some rubbers and metals break peroxide down or corrode |

⚠ Sodium percarbonate is an oxidizer: it needs Form 3 and the supervisor present.

## Dropped 2026-10-01 (do not buy)

| Item | Was for | Why dropped |
|---|---|---|
| Sugar kelp / *Ulva*, mesh cages, holding tank, mini fridge, salad spinner, plastic plant, fine nylon mesh, nitrate/phosphate strips, seaweed-only tank, 22 seaweed flasks | seaweed | live stock kept cold and swapped; kelp dies back above ~18-20 °C; not autonomous |
| Oyster seed, mesh bags, empty-shell bags, 20 L tanks, oyster holding tank, ammonia kit (for oysters), *Isochrysis* / shellfish feed, 13 clearance beakers | shellfish | always filtering (not switchable), live animals, permits, stops feeding in dense blooms |
| Curcumin ≥ 95%, food-grade ethanol, aluminium foil, 28 curcumin flasks | curcumin | blinds the 470 nm fluorometer; dose overlaps zebrafish LD50; one organism tested |
| Servo motor | lowering seaweed panel / shellfish bag | nothing to lower any more (keep it if already bought) |

## Totals

| | Approx. |
|---|---|
| Shared kit + cultures (incl. *Micromonas*, *Nannochloropsis*) + arm A and pilot tanks for two cultures (much of the electronics already bought) | $945-1,205 |
| Aeration (screen + loop run) | $315 |
| Peroxide (screen + loop run) | $315-345 |
| **Both methods** | **about $1,575-1,865 before borrowing; ~$1,100-1,350 if the sponsor lends the microscope, scale, micropipettes, glassware and meters** |

## Open points
- **One dosing pump or nine?** The alerter drives one relay. Each B, C and D tank runs its own schedule, so either each treated tank gets its own relay channel and pump (an 8-channel relay module, ~$10, plus more pumps), or one alerter-driven tank is the full demonstration and the others are switched by hand at the logged times. Decide before `LOOP_PREREG.md`, and report it under autonomy.
- **Air supply for the aeration tanks:** 0.6 L/min per litre is 2.4-6 L/min per tank. Check the pumps reach that through the stones; if not, run the aeration tanks at 4 L.
- ***Nannochloropsis* purity:** aquarium cultures may carry other algae or bacteria. Check under the microscope and sub-culture before the screen.

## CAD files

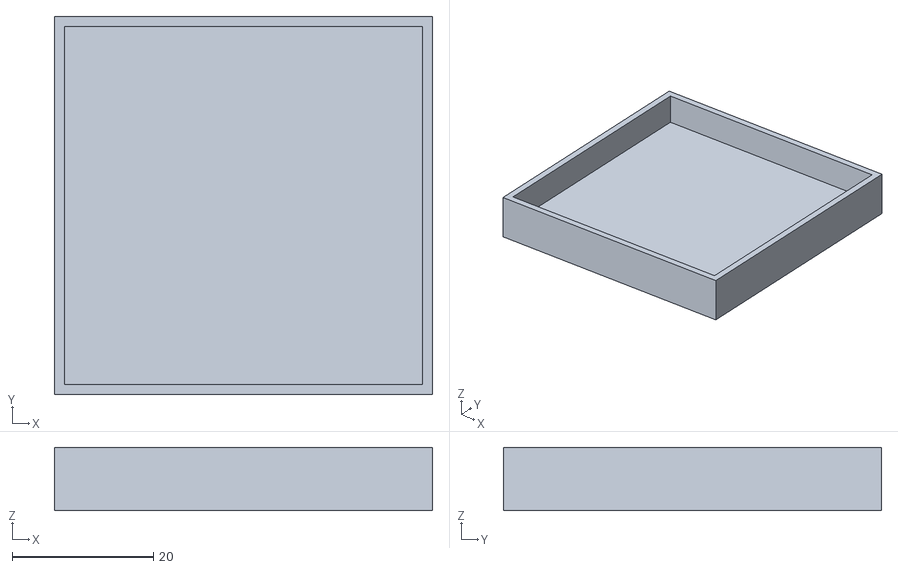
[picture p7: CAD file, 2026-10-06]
hardware/fluorometer_box/fluorometer_cap.stl
53.6 x 53.6 x 9.00

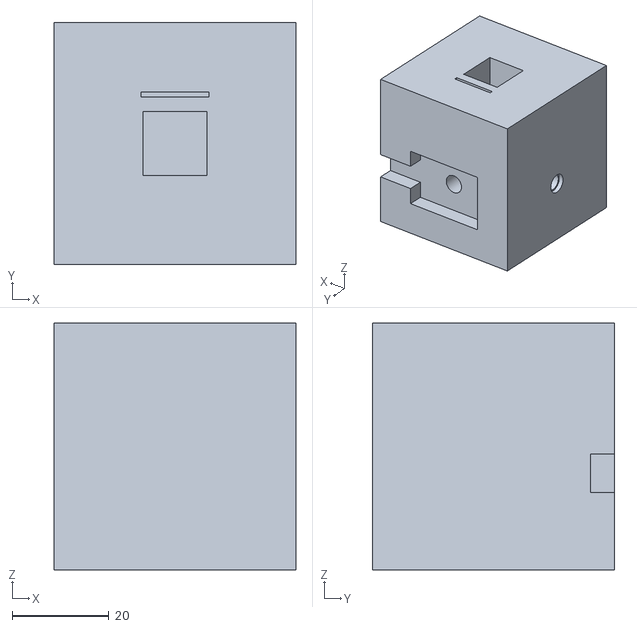
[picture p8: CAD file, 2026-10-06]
hardware/fluorometer_box/fluorometer_box.stl
50.0 x 50.0 x 51.0

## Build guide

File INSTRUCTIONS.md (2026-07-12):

# HAB Bloom Predictor — Setup & Usage

## Environment setup
1. Install Anaconda from anaconda.com
2. Open Anaconda Prompt and run:
   conda create -n hab python=3.11
   conda activate hab
   pip install numpy pandas xarray netCDF4 matplotlib cartopy scikit-learn torch torchvision earthaccess

## Running scripts
Always activate the environment first:
   conda activate hab

Then run everything from the repo root (scripts use root-relative data/ paths):
   python src/data/download_modis.py       # download satellite data
   python src/viz/visualize.py             # plot chlorophyll map
   python src/models/final_evaluation_threshold_sweep.py   # final evaluation
   python src/deploy/daily_inference.py --date 2022-07-19  # daily inference

## Data
- Raw NetCDF files go in data/raw/
- Do not commit data/ to GitHub (it's in .gitignore)
- NASA Earthdata login required -- earthdata.nasa.gov

## Project structure
   hab-bloom-predictor/
   ├── data/
   │   └── raw/              # MODIS/satellite NetCDF files (gitignored)
   ├── figures/              # committed output figures
   ├── notebooks/            # exploratory EDA notebooks
   ├── notes/                # paper notes and analysis logs
   ├── src/
   │   ├── data/             # data acquisition & aggregation
   │   ├── features/         # feature engineering
   │   ├── models/           # training, evaluation, tuning
   │   │   └── experiments/  # one-off experiments & diagnostics (do not import)
   │   ├── viz/              # figure & plot generation
   │   └── deploy/           # daily inference pipeline & dashboard
   ├── CLAUDE.md             # run instructions & model card
   ├── INSTRUCTIONS.md       # this file
   └── README.md

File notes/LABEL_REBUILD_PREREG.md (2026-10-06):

# Pre-registration: rebuilding the LIS chlorophyll label on a lab-consistent scale

Written 2026-09-23, **before any model has been re-run on a rebuilt label.** Nothing below
this line has been computed except the descriptive table in §1, which is what prompted it.
Any change to this file after the first model run is logged in §9 with a date and a reason.

## 1. Why this exists

CT DEEP replied on 2026-09-22 that its sampling, analysis methods and analytical laboratory
have not changed in 30+ years. The LIS label (`bloom_28d` in
`src/models/final_evaluation_threshold_sweep.py`, lines 102-112) is built from the
`Chlorophyll` column of `data/hab_features_tidal.csv`, which is the **CTD fluorometer**
reading, not DEEP's extracted **lab** chlorophyll. Matching the two on the same station and
date (`src/models/experiments/sensor_vs_lab_chl.py`, output `data/sensor_vs_lab_chl.csv`,
surface bottle CHLA from the UConn ERDDAP `DEEP_Nutrient` dataset):

| Years | Sensor ÷ lab (median, per year) | Lab share > 10 µg/L | Sensor share > 10 µg/L |
|---|---|---|---|
| 1994-1999 | 2.08-4.79 | 0.00-0.18 | 0.17-0.62 |
| 2003-2008 | 0.96-1.37 | 0.07-0.23 | 0.14-0.35 |
| 2009-2013 | 1.77-3.22 | 0.03-0.18 | 0.42-0.59 |
| 2016-2021 | 0.80-1.05 | 0.05-0.19 | 0.03-0.11 |
| 2022-2024 | 0.86-1.31 | 0.05-0.09 | 0.03-0.13 |

`Corrected_Chlorophyll` sits at 0.82-1.35 of the lab in every year from 1995 to 2021, but it
is empty for 2022-2024.

Two things overlap, and they have to be kept apart:

1. **A sensor scale change.** The fluorometer read roughly two to three times the lab in
   1994-1999 and 2009-2013, and about the same as the lab from 2016 on. The 2014 "cliff" in
   the label (sensor share 0.42-0.59 → 0.03-0.11) is mostly this.
2. **A real, temporary low period in the lab record.** Lab exceedance share was 0.10-0.23 in
   2008-2011, 0.03-0.07 in 2012-2017, and 0.10-0.19 in 2018-2021. This matches DEEP's
   recollection of a region-wide change "around 2011". Lab sample counts are low in 2012
   (74) and 2013 (101), so the start date is soft.

**Consequence:** the training years carry inflated exceedances in 1994-1999 and 2009-2013,
and the chlorophyll features (current value, lags, rolling means, trend, anomaly,
climatology, neighbour means) inherit the same scale drift. The test years 2023-2025 are
affected much less, because the sensor sits near the lab there.

## 2. Question

When the LIS chlorophyll series is put on a lab-consistent scale, for the label and for
every chlorophyll-derived feature, what are the test-set skill numbers, and how far do they
move from the ones currently reported?

## 3. Series (defined now, not after seeing results)

| Name | Chlorophyll value used for the label and all chlorophyll features | Role |
|---|---|---|
| **S0** | raw `Chlorophyll` (sensor), as now | reference: current pipeline |
| **S1** | `Corrected_Chlorophyll`; where it is missing, raw `Chlorophyll` multiplied by that year's median `Corrected_Chlorophyll / Chlorophyll` over rows that have both (at least 30 such rows); if a year has fewer than 30, raw `Chlorophyll` ×1 (this covers 2022-2024, where sensor ÷ lab was 0.86-1.31) | **primary** |
| **S2** | raw `Chlorophyll` divided by that year's median sensor ÷ lab from `data/sensor_vs_lab_chl.csv`; 2025, which has no lab data yet, uses the 2016-2024 median ratio | sensitivity: independent of DEEP's correction |
| **S3** | label from lab surface CHLA only; features from S1; a row is kept only if its forward 28-day window contains at least one lab sample; the test set is therefore 2023 plus 2024 up to 2024-05-07 (28 days before the last lab date, 2024-06-04) | sensitivity: the lab as referee |

Why S1 is primary: it is DEEP's own lab-anchored product, it covers 1993-2021 and 2025
directly, and it keeps every station-day. Its one assumption is the gap fill for
2022-2024. S2 and S3 each remove a different assumption.

**What "S1 is primary" means:** S0 is known to be on an inconsistent scale across the
training years, so **S1 replaces S0 as the headline whichever way the numbers move.** The
choice is made on measurement validity, now, not on results later.

## 4. Held fixed

Everything except the chlorophyll values: logistic regression, `C=0.05`,
`class_weight='balanced'`; the same 35-feature list; train 1993-2019, validation 2020-2022,
test 2023-2025; median imputation and scaler fitted on training rows only; the 10 µg/L cutoff;
the 28-day forward label rule; seed 42; `bootstrap_ci.py` with station-year clusters,
2000 draws.

Operating points reported:
- **t = 0.60**, the locked headline threshold, applied unchanged.
- **The validation-F1-maximising threshold** on the 0.10-0.90 grid (step 0.05), chosen on
  2020-2022 only. The current script's `best_t` is chosen on test F1; that is not used here.

## 5. Implementation, and a gate before any model runs

1. `src/models/label_rebuild.py` writes `data/hab_features_tidal_S1.csv`, `_S2.csv` and
   `_S3.csv`. Each is a copy of `hab_features_tidal.csv` with `Chlorophyll` replaced by the
   series and every chlorophyll-derived column recomputed (`chl_lag1`-`chl_lag4`,
   `chl_climatology`, `chl_anomaly`, `chl_anomaly_pct`, `neighbor_chl3_mean`,
   `neighbor_chl3_lag1`). The rolling means and `chl_trend` are already recomputed inside
   the evaluation script. The feature code is copied from `build_features()` in
   `src/transfer/iec_zero_shot.py` (lines 93-130), not imported.
2. `final_evaluation_threshold_sweep.py` gains `--input` (default unchanged:
   `data/hab_features_tidal.csv`), and for S3 a `--label-col` that reads a prebuilt label
   instead of computing one.
3. **Gate G1:** run the builder on raw `Chlorophyll` (S0). Every recomputed column must
   match the existing column in `hab_features_tidal.csv` to within 1e-9 on every row where
   both are present. If it doesn't, the builder is wrong; fix it before running anything
   else. Running with the default `--input` must reproduce test AUC 0.8150 exactly.
4. **Gate G2:** the S1 and S2 series, compared with lab CHLA on matched pairs, must sit at a
   median ratio of 0.75-1.35 in every year with 50 or more pairs. (S1 is already known to
   pass for 1995-2021; the gate exists to catch a bug in the gap fill or the join.)

## 6. Predictions (graded afterwards; not decision rules)

| # | Prediction | Reasoning |
|---|---|---|
| P1 | S1 training positive rate falls by at least 40% relative to S0 | sensor ÷ lab was 2-3× in 1994-1999 and 2009-2013 |
| P2 | S1 test base rate is within 2 percentage points of S0's 7.2% | 2023-2024 are filled from the raw sensor; only 2025 changes |
| P3 | S1 test AUC is within ±0.05 of 0.815 | the features the model leans on are relative (anomaly, trend, neighbours), so a scale fix should move ranking less than it moves the base rate |
| P4 | S1 precision at t=0.60 differs from 0.500 by more than its own CI half-width | a different training base rate shifts the calibration of `class_weight='balanced'` probabilities, and 0.60 was chosen on the S0 scale |
| P5 | S2 lands within ±0.03 AUC of S1 | two routes to the same lab scale |

## 7. How the result is reported

- S1 becomes the headline for every LIS number that depends on the label, with S0 alongside
  once, labelled as "original sensor-scale label".
- If S1 and S2 differ by more than 0.05 in test AUC, or their lift intervals don't overlap,
  that disagreement is reported as the finding, and neither is called the answer.
- S3 is reported with its (small) n and interval, as the lab-referee check.
- Every prediction in §6 is graded right or wrong in `notes/SCIENTIFIC_METHOD.md`.

## 8. What has to be re-run after S1, in this order

Each depends on the LIS label or the chlorophyll features:

1. `src/models/final_evaluation_threshold_sweep.py` → `bootstrap_ci.py` (headline numbers,
   CLAUDE.md table)
2. `src/models/station_specific_models.py` (per-station operating points)
3. The 21-day locked operating point (README: precision 0.125, POD 0.875, t*=0.35)
4. `src/models/decision_value.py` (15.4 → 8.3 visits per bloom)
5. `src/transfer/iec_zero_shot.py` (the model is trained on DEEP rows, so the IEC transfer
   result moves too; IEC's labels are IEC lab values and don't change)
6. The rarity/overlap comparison with Narragansett (OVL 0.44 vs 0.52; `lr_geometry`)
7. `notes/KEY_NUMBERS.md`, CLAUDE.md, the README, the UConn deck and the board

Narragansett, the 74-site transfer and the device work do not use the LIS label and are
unaffected.

## 9. Changes after the first run

Logged 2026-09-23. All three were made **before** any model was fit on S1, S2 or S3.

1. **`bloom` dropped from the rebuilt files.** Gate G1 failed on its first run for one
   column, `bloom`, which was aggregated from profile rows and agrees with
   `Chlorophyll > 10` on only 93.5% of station-days, so it can't be rebuilt from
   station-day values. It is not a model feature: the label is `bloom_28d`, recomputed
   from `Chlorophyll` inside the evaluation script. It is dropped from the rebuilt
   files together with `chl_roll3_std`, `neighbor_chl3_lag2` and `neighbor_chl5_mean`,
   which are also unused and not reproducible. G1 then passed on all 14 rebuilt
   columns (max difference 2.3e-13), and the S0 file reproduced test AUC 0.8150,
   AP 0.3565 and precision 0.500 at t=0.60 exactly.
2. **Where the climatology comes from.** `chl_climatology` is a station×month mean over
   every **profile** reading, all years (notebooks/eda_labels.ipynb, cell 11), so each
   series is also applied to `data/hab_labels_final.csv` before averaging. The
   neighbour feature uses 111·cos(41.1°) km per degree of longitude, the value that
   reproduces the original exactly.
3. **Bootstrap.** AUC and lift intervals come from `label_rebuild.py compare`, not
   `bootstrap_ci.py` (which reports precision, recall and F1 only). It uses the same
   scheme: station-year clusters, 2000 draws, seed 42.

## 10. Result (2026-09-23)

`data/label_rebuild_results.csv`; test 2023-2025.

| Series | Test n / positives | Base rate | AUC [95% CI] | t | Precision [CI] | Recall | Lift [CI] |
|---|---|---|---|---|---|---|---|
| S0 sensor (original) | 1,034 / 74 | 0.072 | 0.815 [0.734, 0.876] | 0.60 | 0.500 [0.360, 0.650] | 0.486 | 6.99 [4.97, 11.26] |
| **S1 corrected (headline)** | 1,034 / 65 | 0.063 | **0.804 [0.706, 0.878]** | 0.60 | **0.316 [0.179, 0.424]** | 0.477 | **5.03 [3.50, 6.88]** |
| S1, validation-F1 t | | | | 0.75 | 0.400 [0.133, 0.550] | 0.215 | 6.36 [2.63, 9.79] |
| S2 lab-calibrated | 1,034 / 98 | 0.095 | 0.799 [0.730, 0.852] | 0.60 | 0.383 [0.276, 0.466] | 0.469 | 4.05 [3.17, 5.32] |
| S3 lab label only | 161 / 15 | 0.093 | 0.760 [0.522, 0.915] | 0.60 | 0.471 [0.159, 0.778] | 0.533 | 5.05 [2.69, 11.36] |

The training positive rate went from 22.7% (S0) to 5.5% (S1) and 8.9% (S2).
Validation-F1 thresholds: S0 0.35, S1 0.75, S2 0.40, S3 0.45.

Predictions (§6):
- **P1 right:** training rate fell 76% (needed at least 40%).
- **P2 right:** test base rate 7.2% → 6.3%.
- **P3 right:** AUC 0.815 → 0.804.
- **P4 right:** precision fell 0.184, more than S1's CI half-width of 0.12.
- **P5 right:** S2 is 0.005 AUC from S1.

§7 disagreement check: S1 and S2 differ by 0.005 AUC and their lift intervals overlap,
so they agree.

## 11. Amendment A1: DEEP's answer, and series S4 (2026-09-23, before S4 is run)

K. O'Brien-Clayton (CT DEEP) replied at 11:52: *"I would not use the in situ fluorometer
data at this point. Use the lab data."* A DEEP seasonal is comparing lab and in-situ
chlorophyll. The CTD changed from a SeaBird to a YSI EXO2 around 2009/2010, consistent
with sensor ÷ lab rising from 1.37 (2008) to 1.84 (2009) and 2.25 (2010). Whether
pre-2010 `Corrected_Chlorophyll` was lab-corrected has been asked of DEEP and is not yet
answered.

S1 is a corrected fluorometer series, so it no longer matches the agency's guidance.
Under the rule at the end of this file, S1 is kept and reported, and a new series is
added.

| Name | Chlorophyll for features | Label | Role |
|---|---|---|---|
| **S4** | lab surface CHLA on station-days that have one; empty otherwise (the pipeline's training-median imputation handles gaps, unchanged). Lags, rolling means, trend and neighbour means use the same recipe on this series; `chl_climatology` is the station×month mean of all lab surface samples, all years (the lab analogue of the original's all-years profile mean) | `bloom_28d_lab`, as S3 | **headline label definition** |

Test set: as S3, 2023-01-01 to 2024-05-07, because the ERDDAP lab record ends
2024-06-04. That is roughly 160 rows and 15 events, so:

- **Headline rule.** S4 is the label definition the project reports as its main result,
  because the agency that collects the data says to use it. Its numbers are always shown
  with intervals, and S1 (AUC 0.804, lift 5.03) is shown beside it as the full-coverage
  lab-scale estimate. If S4's AUC interval is wider than 0.30, the talk and board say
  plainly that the lab-only test is too small to pin down skill, and they don't quote a
  single number without its interval.
- **Extension.** When DEEP releases lab chlorophyll after June 2024, the S4 test set is
  extended with **no code or parameter changes** and re-reported. Only then is it called
  final.
- **Predictions:** P6: S4 test AUC is in 0.65-0.85. P7: S4 AUC is no more than 0.03
  above S3's 0.760, since S4 loses the fluorometer's day-to-day detail and keeps the same
  label.

**Implementation note (before S4 ran).** The lab series has gaps, so `chl_trend` (a
4-point rolling slope) failed on windows containing a missing value. The slope now
skips missing points, in both `label_rebuild.py` and the evaluation script. On windows
without gaps it is identical: G1 still passes, and S0 and S1 reproduce 0.8150 and 0.8036.

**DEEP confirmation (2026-09-23, after S1 and S4 had run).** M. Lyman (CT DEEP),
answering whether pre-2010 corrected chlorophyll was corrected using the lab data:
"Yes, the corrected data has been corrected against the lab data." This confirms S1's
basis for the years it asks about. Our own check shows `Corrected_Chlorophyll` at
0.82-1.35 of lab through 2021, so empirically it is lab-anchored after 2010 as well.
Still unconfirmed: why the field is empty for 2022-2024, where S1 falls back to the raw
sensor (sensor ÷ lab 0.86-1.31 in those years). No series definition changes.

## 12. Result for S4 (2026-09-23)

| Series | Test n / positives | Base rate | AUC [95% CI] | t | Precision [CI] | Recall | Lift [CI] |
|---|---|---|---|---|---|---|---|
| **S4 lab only** | 161 / 15 | 0.093 | **0.782 [0.595, 0.921]** | 0.60 | 0.467 [0.000, 0.667] | 0.467 | 5.01 [0.00, 9.87] |
| S4, validation-F1 t | | | | 0.50 | 0.421 [0.000, 0.571] | 0.533 | 4.52 [0.00, 9.57] |

Validation AUC 0.847 on 310 rows. Training positive rate 15.3% (3,267 rows).

- **P6 right:** 0.782 is within 0.65-0.85.
- **P7 right:** 0.782 is no more than 0.03 above S3's 0.760.
- **Headline rule triggered.** The AUC interval is 0.326 wide, more than 0.30, so the lab-only
  test is too small to pin down skill. It is reported as "consistent with S1, not yet
  measurable on its own": the point estimates agree (0.782 against 0.804; lift 5.0
  against 5.0), and the S4 intervals include everything from barely-above-chance to
  excellent. S4 becomes final once DEEP's post-June-2024 lab data extend the test set.

## Open questions to CT DEEP / UConn

Sent 2026-09-23 (reply-all to DEEP, O'Donnell, Todd and the others on the thread):
- Did the CTD fluorometer, or its calibration, change around 2014?
- Is the corrected chlorophyll field the one DEEP recommends?

Not yet asked: why `Corrected_Chlorophyll` is empty for 2022-2024. Hold this for the reply
to DEEP's answer, or for the UConn talk.

If DEEP's answer changes the definition of S1 (for example, a different correction for the
gap years), that change is logged in §9 **before** S1 is run, or, if S1 has already run,
as a new series S4 with S1 kept and reported.

## 13. Amendment A2: DEEP lab data through July 2026 (2026-09-23, before any is received)

M. Lyman (DEEP) offered lab chlorophyll-a through July 2026 for all stations; requested
the same day. These rules are fixed now, before a single new value has been seen.

- **Where the new values are used.** DEEP's file is used **only for sample dates after
  2024-06-04**, the last ERDDAP lab date. Before that, ERDDAP stays the sole source, so
  training (≤2019) and validation (2020-2022) rows are unchanged, and the model is not
  refit. It is the same S4 model as in §12.
- **The 2026 wall.** No 2026 value enters any feature, label or test row. S4 test rows are
  2023-01-01 to 2025-12-03 (the last date whose 28-day window closes by 2025-12-31).
  2026 samples are saved to `data/holdout_2026/`, untouched, and are not analysed or shown
  until J. O'Donnell agrees, because his student publishes 2026 observations first. Any
  later use gets its own pre-registration.
- **Overlap check.** Wherever DEEP's file and ERDDAP both have a value before
  2024-06-04, the number of disagreements greater than 0.1 µg/L is reported. ERDDAP is not
  replaced there.
- **Code.** Same `label_rebuild.py` and evaluation script; the only change is the lab
  input, which gets a second file. No parameter, threshold or feature changes.
- **Predictions.** P8: extended S4 test AUC is within ±0.07 of S1's 0.804. P9: its 95%
  interval is narrower than 0.30, which lifts the §11 "too small" flag. If P9 fails, S4
  stays "consistent with S1, not measurable on its own".

## 14. Downstream re-runs on S1 (§8), 2026-09-23

How they were run: `HAB_FEATURES_CSV=data/hab_features_tidal_S1.csv HAB_OUT_TAG=_S1` in
`locked_pipeline.py` and `station_specific_models.py`. Unset, both leave every path
unchanged. Plumbing check: `reference_baselines.py` run through the rebuilt S0 file
reproduces `data/reference_baselines.csv` exactly (max difference 0.0). Outputs are the
`*_S1.csv` / `*_S1.png` files beside the originals, and none of the originals, including
`data/station_thresholds.csv`, which the deployed pipeline reads, were overwritten.

| Result | Original (sensor label) | S1 (lab-consistent label) |
|---|---|---|
| **21-day operating point**, station-day, t*=0.35 (frozen), test 2023-25 | precision 0.132, POD 0.917, lift 2.63, base 5.0% (48 events) | precision 0.117, POD 0.744, lift 2.59, base 4.5% (43 events) |
| Model vs always-alert, lift difference [CI] | +1.65 [1.20, 2.23] | +1.59 [1.07, 2.22], still clearly better |
| Model vs station×month climatology | +0.33 [-0.01, 0.71], not clearly better | +1.59 [1.07, 2.22], **but see note** |
| Basin-day | lift 1.37, 12 events | lift 2.14, 9 events; vs always-alert +0.43 [-1.00, 1.77], not clear |
| **Decision value**, V=8 visits/month: calendar → alert (top-V) | 15.4 → 8.3 visits per bloom | **17.8 [9.6, 55.0] → 9.7 [5.5, 26.6]**; causal t* 7.8 [3.9, 40.4] |
| **Per-station** (western five, test 2023-25) | C1 1.000, 02 0.625, 01 0.500, A4 0.625, B3 0.556 precision | none clears P>0.50 with R>0.40; pooled global @0.60 P 0.375, R 0.724 |
| **Rarity/overlap** (onset rows, 21 d): LIS base, AUC, OVL | 0.036, 0.855, **0.445** | 0.026, 0.770, **0.620** (Narragansett unchanged: 0.347, 0.810, 0.516) |

**Note on the climatology row.** Under S1, the climatology baselines' own
validation-chosen threshold went to t=0, which alerts on everything and makes them
identical to always-alert. The "+1.59, clearly better" against climatology is therefore
an artefact of that selection rule degenerating, **not** evidence that the model beats
climatology. It is reported as "not tested fairly under S1". The original finding (no
clear advantage over climatology) stands as the honest statement.

**The rarity finding changes.** Under the sensor label, the Sound separated the two
classes slightly *better* than Narragansett (OVL 0.445 against 0.516), which supported
"precision follows rarity, not skill". Under S1 the Sound separates them *worse* (OVL 0.620
against 0.516) and is also rarer (base 0.026 against 0.347). Lower precision in the Sound
is now rarity **and** weaker separation. "Not skill" is withdrawn; "mostly rarity" needs
the matched-rarity test re-run before it can be said.

**IEC zero-shot transfer** (`data/iec_zero_shot_results_S1.csv`; the model is refit on S1
DEEP rows ≤2019; IEC's labels are IEC lab values and don't change):

| Primary: 2020-25 IEC onset rows, >10 µg/L, 21 d (949 rows, 126 events) | Original | S1 |
|---|---|---|
| Model at t=0.60: lift [CI] | 1.84 [1.59, 2.11] | **1.57 [1.41, 1.75]** |
| Model AUC [CI] | 0.732 [0.680, 0.782] | **0.707 [0.656, 0.760]** |
| Station-month climatology: lift, AUC | 1.50, 0.733 | 1.50, 0.733 (unchanged) |

The transfer still holds against always-alert: the whole lift interval is above 1, and it
sits inside the originally pre-registered band of 1.2-1.8 rather than at its top. Against
climatology the model's point lift is now nearly equal (1.57 against 1.50, intervals
overlapping), and its AUC is now slightly *below* climatology's. Honest statement: the
frozen model transfers to a second agency's lab record better than chance, and no better
than a station-by-month calendar.

## 14b. Defaults switched to S1, and the remaining re-runs (2026-09-23)

**Defaults.** `locked_pipeline.py`, `final_evaluation_threshold_sweep.py`,
`station_specific_models.py` and `rolling_origin_cv.py` now read
`data/hab_features_tidal_S1.csv` by default. `HAB_FEATURES_CSV=data/hab_features_tidal.csv`
reproduces the sensor label.

- Gate: the default run gives AUC 0.8036 and 31 TP of 65 at 0.60 (S1). The env-var run gives
  0.8150 (the original).
- Every overwritten canonical output was first copied to `data/archive_sensor_label/` (36 files).
- The canonical `reference_baselines`, `decision_value` and `lr_geometry_summary` are identical to
  their `_S1` copies (max difference 0), and so is the IEC primary row (lift 1.571).

| Result | Sensor label (archived) | S1 (now default) |
|---|---|---|
| **Rolling-origin CV, 21 d** (`rolling_origin_cv.py --horizon 21`), README headline | pooled AUC **0.852**, 4,040 rows / 156 events, 2015-2025 | pooled AUC **0.772**, 3,653 rows / 121 events, 2016-2025 (2015 fold skipped: too few validation positives) |
| Rolling-origin CV, 28 d (default) | not comparable (the archived file came from a different run: 2,650 rows) | pooled AUC 0.717, 4,040 rows / 180 events |
| **Frozen t*=0.35**, test 2023-25 (`warning_robustness.py`) | POD 0.875, precision 0.125 | POD **0.791** [0.636, 0.906], precision **0.114** [0.063, 0.163], FAR 0.886, 34 TP / 265 FP / 9 FN |
| **Pre-registered selection rule** (highest t with CV-selection POD ≥ 0.8, `warning_operating_point.py --test-from-cv`) | t* = 0.35 | **t* = 0.20**; at 0.20 test POD 0.907, precision 0.072 |
| Point of no return (`point_of_no_return.py`) | 617 pre-onset obs; analogue risk peak 0.62, median 0.04; model counterfactual 65% summer events locked → 0% | 544 obs / 153 events; analogue peak **0.42**, median 0.02; summer M1 counterfactual 42% → **0%** once physics moves. Conclusion unchanged, and stronger |
| Daily inference | trains through the last labelled date | trains on 11,357 S1 rows (bloom rate 3.3%). Every station is stale on 2026-09-23 (newest visit 2025-08-28), so nothing is scored |

**Open decision (for the user, not made here):** re-applying the pre-registered
POD ≥ 0.8 rule on S1 moves t* from 0.35 to 0.20. `daily_inference.py` keeps the frozen
0.35 until the user decides. Both are reported.

**IEC lab change (K. O'Brien-Clayton, 2026-09-22).** From `data/iec_wqp_raw.csv`
(`ResultAnalyticalMethod/MethodIdentifier`; `LaboratoryName` is blank): IEC chlorophyll
used Standard Methods 10200H through 2016, both methods in 2017, and EPA 445.0 in every
year 2018-2025. The primary transfer window (2020-2025) and the 2018-2025 variant sit
entirely on EPA 445.0, so the change does not touch them. Only the secondary
"1991-2017 summer-only" scenario spans it. No re-score is needed; this is noted beside
that scenario.

## 15. The live season: label from the lab, inputs from sensors (2026-09-23)

- **The label is lab.** Every retrospective LIS evaluation uses the lab-consistent label (S1, with
  S4 as the lab-only check).
- **Real-time inputs are necessarily sensor inputs.** DEEP's lab chlorophyll arrives months after
  sampling, so a forecast issued in season can't use it. The DEEP CTD fluorometer has sat at
  0.80-1.31× the lab since 2016, so in-season sensor features are near lab scale. That is a
  measured property of 2016-2024, not a guarantee.
- **The prospective season is unaffected.** It is the fork's `src/deploy/prospective_forecast.py`:
  the frozen Narragansett model on the LISICOS buoys (WLIS, EXRX), each site at its own frozen p75
  from `data/prospective/site_p75.csv`. It never uses the DEEP CTD, so DEEP's advice doesn't
  change its pre-registered scoring rule.
- **Added now, before the season:** once DEEP lab samples from stations near the buoys exist
  for the prospective window, report the share of buoy alerts followed within 7 days by a lab
  exceedance (>10 µg/L) at the nearest DEEP station. It is secondary and descriptive, and never
  replaces the primary score.
- **Unchanged:** nothing is issued before ISEF Form 1A is signed.

**Late re-runs (after a memory-pressure stop and restart, 2026-09-23):**
- `basin_search.py` (912 cells, 200-shuffle null). Selected on validation: t=0.35, west of
  -73.2, no season gate, ≥1 station, mean aggregation, validation lift **2.05×**. That sits at
  the **70.5th percentile** of the null (median 1.79×, 95th percentile 2.86×, max 3.71×), so it
  is still INSIDE the null and the conclusion is unchanged ("the search found noise"). The sensor
  label gave 1.84× at the 52nd percentile of a null with median 1.83× and 95th percentile 3.01×.
  Test: 75 basin-days, 20 events, POD 0.500, precision 0.417, lift 1.56× (+0.56× over
  always-alert).
- Fork `cadence_thinning_matched.py` and `lift_at_rarity_cv.py`: `LIS_REF` updated to S1
  (precision 0.117, AUC 0.825, base 0.045, lift 2.59). The Narragansett-side results are
  unchanged, as expected. At matched 5% rarity with daily sampling, precision is 0.09-0.14 (the
  Sound's S1 value, 0.117, sits inside that range). Over nine CV years at T=52.5 µg/L, lift is
  8.48× [5.98, 12.81], and at T=39, 6.92× [5.32, 9.31]; both lower bounds are above the Sound's
  2.59. "At matched rarity, precision falls to the Sound's level" still holds. Together with the
  OVL flip (0.62 against 0.52), the honest wording is "mostly rarity, not only".

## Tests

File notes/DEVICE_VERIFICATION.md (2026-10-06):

<!-- notes/DEVICE_VERIFICATION.md. Independent scientist verification of notes/DEVICE_PROTOTYPE.md (v4),
2026-09-15. Verdicts: WORKS / PLAUSIBLE / UNSUPPORTED per component. -->

# Scientist verification of design v4 (magnetic PAC-kaolin flocculation with in-tank magnetic retrieval)

Lens: does the process work as claimed, and can it run in real water. Verdicts: WORKS (cited evidence at comparable conditions), PLAUSIBLE (mechanism sound, no direct evidence at these conditions), UNSUPPORTED (evidence against, or none). Independent checks this pass (19 web calls, three primary PDFs read in full): the WHOI/EPA ECOHAB final report; Yu et al. 2016 on PAC-clay in seawater; the CoMag magnetite-ballast process; the Bayferrox 318 M data sheet; Golding 2015 marine Al guideline; EPA 2018 Al criteria; Beaulieu 2005 floc resuspension; Vaudrey 2016 embayment N loads; the CT DEEP coastal permit overview; Hu 2013, Cerff 2012, and Fe3O4@SiO2@PAC magnetic seeds. My calculations are marked [calc]; unverifiable items [unverified].

## 1. Flocculation at low density in seawater: PLAUSIBLE, leaning WORKS; one recipe detail works against it

**Encounter rate is not limiting at G ~30 s-1 [calc].** At 0.2 g/L, ~2 um EPK kaolin is ~1.8e7 particles/mL, ~1,800 per cell at 1e4 cells/mL. Orthokinetic collisions of an 8 um cell with clay run at (G/6)(d1+d2)^3 n ~ 0.09 s-1, ~80 per cell over the 15 min slow mix; perikinetic is ~3e-4 s-1, 300x lower, so stating G was right. Clay-clay collisions scale with n^2, so the clay self-flocculates within minutes and cells are mostly taken by sweep: ~3e9 flocs/m3 of 50-100 um settling at 0.3-1 mm/s sweep 5-6 tank volumes in 15 min, giving 70-95% removal at collision efficiencies of 0.2-0.5. This is the "sweep floc" model the EPA/WHOI report adopts.

**Cell density.** The EPA/WHOI report: for K. brevis "eighty percent or higher cell removal was not seen until cell concentration exceeded approximately 1,000 cells/mL", the same rising trend for Heterosigma, A. tamarense and A. sanguinea, and RE correlated with predicted clay-cell collision frequency. 1e4 is 10x above that threshold. In the Corpus Christi bloom mesocosms (530 L), 4 ppm PAC + 0.10 g/L clay gave RE >81%, and "K. brevis, Bacillaria sp., and Skeletonema sp. were removed at about the same level": the only Skeletonema-in-seawater number found, at bloom density. **Chains:** Yu 2017 and the EPA report both say chain diatoms floc readily; no study isolates chain length, so logging it (v4) is the right hedge.

**The seawater penalty is a stock-preparation penalty, and v4 prepares the stock in seawater.** Yu et al. 2016 (PubMed 26763322): PAC-modified clay suspended in seawater dropped to +5.9 mV, aggregated clay-to-clay in the stock, and "larger flocs were observed when PAC-MC suspension prepared by deionized water was added to the algae culture than PAC-MC suspension prepared by seawater"; this is the 0.6 vs 0.2 g/L factor in CLAY s2. The EPA report saw the extreme: PAC-pretreated clay "immediately formed large, baseball-sized aggregates, which immediately sank to the bottom, leaving behind most of the cells in suspension"; diluting PAC into the seawater first and adding clay 20 min later gave a 2-5x RE gain. v4 pastes kaolin, PAC and magnetite in seawater, ages 24 h and holds a 100 g/L seawater stock: the condition both sources say makes small flocs. IOCAS modifies in fresh water, dries, and disperses in seawater only at dosing. R1 chose seawater ageing to buffer acid attack on magnetite; the trade was never examined. **Minimum evidence:** week-1 pilot on one 1e4 culture, three stocks (DI-aged then seawater-dispersed at dosing; seawater-aged as v4; PAC pre-diluted 20 min before plain clay), n = 2, 5 h counts: one afternoon, six jars. If DI-aged wins by >15 points, change the recipe before Nov 6.

**PAC at pH 8.** 0.2 g/L blend is 33 mg/L PAC powder = 5.1 mg/L Al [calc], consuming ~0.3-0.5 of seawater's ~2.3 meq/L alkalinity; pH falls a few tenths, not a process issue. At pH 8 Al precipitates as Al(OH)3 (sweep) with aluminate as the dissolved residual (Golding 2015): an environmental issue (section 3), not a flocculation one. Magnetite at 37 wt% of the blend and its effect on floc formation: [unverified anywhere].

## 2. Magnetic capture in seawater: PLAUSIBLE; strong industrial precedent for the floc, none for the raster

**Kaolin and cells riding with magnetite.** The commercial CoMag process (Evoqua/Xylem) adds finely ground magnetite to metal-hydroxide coagulation; magnetite is "infused into the metal hydroxide floc", flocs settle ~10x faster, and drum magnets recover ">99% of the magnetite" (after a deliberate shear-detachment step, in freshwater wastewater). Seawater analogues: Fe3O4@SiO2@PAC magnetic seeds on ballast-water sediments (IWA WST 2024), where PAC-coated seeds raised algae removal ~20 points; Cerff 2012 (silica-coated magnetic particles, >95% separation of marine P. tricornutum and N. salina by HGMS, 30-77 g algae/g); Hu 2013 (naked Fe3O4 at 120 mg/L, >95% of N. maritima in 4 min, aggregation at alkaline pH helped). Suga 1982's >=10 g Fe/L was direct adsorption without coagulant, not comparable. In seawater (I ~0.7 M) 0.2 um magnetite coagulates with a perikinetic half-life of ~40 s [calc], so during the 60 s drill mix it hetero-coagulates into whatever is present; segregation is unlikely, and the detachment test is the correct gate. WORKS in freshwater; PLAUSIBLE here.

**Pigment properties.** Bayferrox 318 M TDS: Fe3O4 >96.8%, spherical, ~0.2 um, density ~4.6, pH 4-8, not classified hazardous, food-contact listed. No magnetic data on the TDS; patents for the pigment class give Ms 50-91 emu/g and coercivity 20-330 Oe. Ms of the grade actually bought: [unverified]. It does not affect the headline (recovery is magnetite-equivalent against the same powder) but the remanence means the stock self-agglomerates into multi-micron clusters before dosing, which helps capture.

**Free fines are not captured by a moving raster [calc].** A free 0.2 um particle in 25 T/m moves at ~0.02 mm/s (0.5 um: ~0.14 mm/s), minutes to cross 5 mm against ~4 s of dwell under a 4 cm face at 1 cm/s. Only floc-bound or agglomerated magnetite is swept; so magnetite-equivalent recovery measures floc incorporation, which is what you want, and column passes cannot rescue a shortfall.

**>70% from a 16 cm floor.** R2's force budget rechecks [calc]. Gaps: 13 mm lanes between 20 mm faces on 33 mm centres are covered only by the 3 cm overlap; each release cycle strands pad on the tube; 3 mm skids plus a 3.2 mm wall put settled floc 6-8 mm from the pole, the outer edge of the 8-14 mm holding shell; and the raster resuspends the floor (section 3). No data exist for any hand raster; the clay-only blank is the right and only gate. Add a torch photo of the floor after the last pass and a pull test of the tank rinse, so a miss is attributed (left on floor, stranded on tube, or never in floc).

**Tidal-exchange failure mode.** Beaulieu et al. 2005: a 2 mm PAC-clay layer settled 3 h resuspends at ~0.06-0.07 Pa, ~0.09 Pa after 9-24 h; the EPA report adds PAC makes the layer "more fluffy and thus easier to resuspend". A marina ebb of 10-20 cm/s gives ~0.03-0.12 Pa [calc, Cd 0.003], so a fresh layer under a skirt hung 0.3-0.6 m above the bed leaves on the first flood; magnetite ballast should raise the threshold (CoMag settling) but nobody has measured it. Two modes the reviewers missed: uncaptured 0.2 um pigment disperses as a colloid beyond any transect; and LIS bed sediment is glacially sourced with detrital magnetite (heavy-mineral analyses of regional sediment remove magnetite with a magnet; USGS reports susceptibility anomalies from heavy-mineral layers in Chesapeake cores), so the bed sled collects natural magnetic sand and needs a pre-dose baseline on every transect plus a way to tell pigment from grains. [Natural magnetite abundance at the site: unverified.]

## 3. Environmental effects of the blend vs sunk clay: benefit UNSUPPORTED; Al addition is real

**Burial and bottom oxygen.** There is something to remove: the EPA limnocorrals found all brevetoxin in the treated pens in the trapped floc and still there at 96 h; clay raised settled solids 1,426%, volatile solids 527%, BOD rate 31%, with a DO drop on day 2. But no study compares sunk against retrieved floc for DO, sediment nutrients or fauna (RET s5; confirmed none this pass). The counter-evidence is the EPA clam work: fully sedimented clay gave "no significant differences in shell or tissue growth" for juvenile Mercenaria, while clay kept suspended at 0.25 g/L for 2 weeks cut growth ~90%. The documented harm is resuspension, not burial; a raster that scrapes the bed is a resuspension event, and incomplete capture converts a benign layer into suspended fines. "Retrieved is better for benthos": UNSUPPORTED. Minimum evidence: DO and turbidity 2 cm above the tank floor before, during and 1 h after the raster (the diagram already has a DO probe at K), and the tank's T51 count set against the jar count to quantify resuspension.

**Dissolved Al.** Total Al added is 5.1 mg/L (15 mg/L at 3x) [calc]. After PACl coagulation the dissolved residual "increases greatly as pH increases to 8" (PubMed 23422138); tens to a few hundred ug/L is typical, <20 ug/L only with tailored high-basicity PACl. EPA has no estuarine or marine Al criterion (2018: "not enough data"). Golding et al. 2015: marine guideline 24 ug total Al/L; diatom IC10 18 ug/L, mussel embryo EC10 250, oyster embryo EC10 410; toxic forms are aluminate and Al(OH)3(0). Golding 2018 extends this to 18 species as "very high reliability" [values unverified; fetch timed out]. Pacific oyster D-larvae show abnormal development from 150 ug Al/L (ESPR 2023). So treated water is likely above the 95%-protection guideline for hours and within ~2x of bivalve-larva thresholds; Mote's mesocosm clams took up 5x Al without mortality (RET s5). Retrieval does not change dissolved Al, which is set by PAC dose and pH; it removes particulate Al(OH)3 that could re-dissolve slowly. The LaMotte ECR kit cannot resolve this; a partner-lab ICP Al on one 5 h supernatant per arm is the single most valuable environmental number the MVP can add.

**Iron oxide and bycatch.** 54 mg/L particulate Fe per treatment [calc]; the pigment is inert and non-hazardous (TDS); the concern is turbidity from uncaptured fines. Copepods and bivalve larvae are floc-sized and will be enmeshed whether the floc sinks or is captured; no study counts either [unverified, not measurable in the MVP].

## 4. Mass balance [calc]

| Quantity | 20 L bench, 0.2 g/L | 600 m3 field concept, 0.2 g/L [3x] |
|---|---|---|
| Blend (Fe3O4 : kaolin : PAC = 20 : 25 : 9) | 4.0 g (1.48 / 1.85 / 0.67 g) | 120 kg (44 / 56 / 20 kg) [360 kg] |
| Al added (PAC 29% Al2O3) | 0.10 g = 5.1 mg/L | 3.1 kg [9.3 kg] |
| Fe added (Fe3O4, 72.4% Fe) | 1.07 g = 54 mg/L | 32 kg [96 kg] |
| Algal dry mass (1e4 cells/mL, 50 pg/cell) | 0.01 g | 0.3 kg (1.2 kg at 20 ug Chl/L) |
| Wet floc (5-10% bench; 8% field) | 40-80 g | 1.5 t [4.5 t] |
| Algal N (3.1% of AFDW, ash ~30%) | 0.2 mg | 6-25 g |
| Adsorbed DIN (10 uM, 50% adsorbed) | ~1.4 mg | ~40 g |
| N exported per treatment | ~2 mg | 0.05-0.1 kg |

v4's figures (120 kg, 0.3 kg algae, 1.5 t wet, 0.01-0.04 kg N, ~0.15 kg with adsorbed N) recheck. Comparison: Vaudrey's 2016 slides state 1.3 kg N per person per year delivered to the water's edge (LIS average), embayments carrying 18% of the coastal-watershed load, 67% of it sewer and septic; no per-embayment table was extractable [Milford Harbor load: unverified]. A 10,000-person embayment watershed delivers ~36 kg N/day; one 600 m3 treatment exports 0.1-0.3% of one day's load, about one resident's load for 2-4 weeks, while adding 3 kg Al and 32 kg Fe. That 30 kg of metal per 0.1 kg N is why the board's refusal to state a nutrient credit is correct.

## 5. Energy, time, labour vs the forecast lead and settling time [calc]

Bench: <0.05 kWh per run (drill 8 Wh, paddle ~0.5 Wh, ESP32 ~24 Wh/day); hands-on ~1 h for T0-T51, ~1.5 h pad workup, three 35 min counts, a 24 h count and a 7 d regrowth read: 4-5 h per tank run plus revisits. Consistent with the calendar.

Field concept: 600 m3 at 160 m3/h needs ~10-15 kW for 3.75 h (40-55 kWh); a low-intensity drum at 0.05-0.1 kWh/m3 adds 30-60 kWh; ~100 kWh per treatment, dwarfed by 2-3 people for 6-8 h, 0.8-2.4 m3 of 150 g/L slurry (13-40 L/min in the hour before slack) and 1.5-4.5 t of wet sludge. The sequence is not physically consistent as written: flocs reach a 2 m bed in 0.5-2 h, so with dosing 1 h before low slack the layer forms as the flood starts, and the bed vacuum then runs 1.6-3.75 h under 10-20 cm/s at or above the Beaulieu threshold, inside a skirt deliberately open at the bed. The 7-day lead is not the problem (it lets you pick the slack); the 1-2 h slack against a 2-4 h capture is. Consistent versions: (a) a closed-bottom mesocosm (bag or cod-end limnocorral; the EPA Sarasota pens were 2 m diameter, 3 m deep), or (b) capture during the flocculation window, pumping the cell through the drum while flocs are suspended, which is the one operational advantage magnetic capture has over settling and which the settle-then-raster sequence does not exploit. Add "sequence not yet consistent with tidal timing" to weakness 8.

## 6. Regulatory: removal is not treated differently from deposition; a student gets a mesocosm authorisation only through an institutional permittee

The CT DEEP coastal permit overview (CGS 22a-359 to 363h) lists as regulated "discharge of dredged material or ... the placement of rock, soil or other fill material in tidal waters" and maintenance dredging; tracks are individual permit, Certificate of Permission (45 d, 90 d with more information) and General Permits (~90 d); it contains no temporary, scientific, research or educational exemption. Clay is "soil or other fill material"; a sled or vacuum removing bed material is dredging; both are regulated and nothing distinguishes them (consistent with RET s8). A clay-PAC-magnetite slurry released to tidal water is a discharge under CGS 22a-430; the general permits found cover stormwater, dewatering and industrial categories, none research releases, so an open-cell release needs an individual discharge permit plus the coastal permit, CWA 401, public notice and a USACE authorisation under the CT General Permit [GP category for the discharge itself: unverified]. Florida's precedents needed an NPDES-type permit and a permitted area; NOAA's own clay demonstration runs under a NEPA Programmatic EA. Realistic student path: a closed 1-10 m3 mesocosm hung from an existing dock with no discharge (contents to the school drain per the Al policy) is a temporary structure: COP or GP with USACE GP self-verification, ~45-90 days, with the DEEP/UConn partner as applicant. The curtain cell, Rhodamine and bed sled are 6-18 months and agency-led.

## 7. Forecast-to-dose logic: sound as a demonstration trigger, UNSUPPORTED as mitigation

`alert` is P(station chl exceeds its own p75 within 7 d) >= 0.50 and `onset_row` restricts to days with chl <= p75. A p75 exceedance is by construction a top-quartile day, not a harmful bloom; the trigger fires on the routine seasonal rise. That is fine for a demonstration and honest as a pre-emption test only in an enclosed volume; in a flushed slip v4 concedes it cannot work (s4), and no deployment has dosed pre-emptively on a forecast (RET s9).

**Wasted doses per station-season [calc from the AER duty cycle and the CLAUDE.md table].** ~17 weekly summer rows. At 0.60: 7% flagged, recall 0.48, precision 0.50 (~7% summer base rate): 1.2 alerts, ~0.6 wasted. At 0.50: 15% flagged, recall 0.60, precision ~0.29: 2.6 alerts, ~1.8 wasted. Per station at 0.60: A4 flags 57% of visits at precision 0.625, ~10 alerts, ~4 wasted (the issue_date lockout halves doses, not the ratio); B3 48% at 0.556, ~8 alerts, ~3.6 wasted; C1 10% at 1.0 on 7 positives, ~1.7 alerts, few wasted but n is tiny. At IEC (0.24 vs 0.13) three of four doses are wasted. One wasted field dose is 120-360 kg product, ~100 kWh, a working day and 3-9 kg Al plus 32-96 kg Fe in the water; at the bench, 4 g. So the gate is defensible for January and for a mesocosm; as an open-water trigger the false-alarm Al load roughly equals the true-alarm load, and true alarms are not shown to prevent anything. Keep VERIFY (24 h count < 0.3 C0, hard stop after one retry); do not describe the gate as "predicting a bloom".

## 8. Overall

| Component | Verdict | Basis | To reach WORKS |
|---|---|---|---|
| Flocculation (PAC-kaolin, 1e4 cells/mL, 25-30 psu) | PLAUSIBLE | EPA/WHOI >81% at 0.10 g/L + PAC; PMC12390390 100% at 1e4; Yu 2016 seawater-stock penalty applies to v4's recipe | Week-1 three-stock pilot; H11a at n = 3 |
| Magnetite incorporation in floc | PLAUSIBLE (WORKS freshwater) | CoMag >99% ballast recovery; Fe3O4@SiO2@PAC seeds in ballast water; Cerff 2012, Hu 2013 | Detachment test <30% non-magnetic residue |
| Magnetic capture (hand raster, 0.3 T at 3 mm) | PLAUSIBLE | Force budget holds; no raster data; free fines not captured | Clay-only blank >=70/80% twice, misses attributed |
| Pad workup | PLAUSIBLE | Arithmetic correct; 0.2-3 gf near drift floor | Calibration r^2 and <=2 mg drift logged daily |
| Instruments | Counts WORKS; Chl limited; Al kit UNSUPPORTED as a number | Poisson +/-14% at 200 cells; ECR Fe-interfered | Partner-lab ICP Al on 5 h supernatant |
| Controller | WORKS (as trigger) | Ledger contract checked by R1 | Unattended dose by Dec 4 (gated) |
| Field concept | UNSUPPORTED | Tidal timing inconsistent; 0.06-0.09 Pa resuspension; natural magnetite confounds sled; permits agency-led | Closed mesocosm; capture during flocculation |
| "Retrieved better than sunk" | UNSUPPORTED | No comparison exists; sedimented clay benign to clams, suspended harmful; dissolved Al independent of retrieval | Floor DO/turbidity during raster; ICP Al; permitted mesocosm |

**Three biggest risks to the January result.**
1. Seawater-aged stock under-flocculates at 0.2 g/L (Yu 2016; EPA "baseball aggregates"); H11a lands at 40-60% and the 0.6 g/L rerun costs a batch week. Mitigation is one week-1 afternoon and a recipe change before Nov 6.
2. Recovery is measured after a raster that resuspends its own floor, and pad sheds on every release: total-solids recovery can miss 70% while magnetite-equivalent passes, and the board shows two numbers that disagree for no stated reason. Attribute every miss and report resuspension.
3. Measurement floor: 0.2-3 gf pull tests on a ~2 mg-drift balance and counts capped at 200 cells give CIs wide enough that "lower bound > 50%" at n = 3 fails on noise if true RE is ~70%. Pre-register that mean >= 70% with a lower bound of 40% reads "consistent, underpowered", not failed.

**Section 9 board sentences if H11a-b pass.** Sentence 1: mostly, with one fix: the jars were not dosed "when a test forecast row alerted", only the tank runs were; split removal (jars) from trigger (tank). Sentence 2: supportable on recovery; qualify "no published study had measured the recovered fraction in seawater" to "no HAB clay study", since Cerff 2012 and Hu 2013 measured magnetic separation of marine algae in culture and CoMag reports magnetite recovery in freshwater. Sentence 3: supportable as written. Add to the reject list: "predicts blooms" (it predicts a p75 exceedance) and "removes aluminium" (it adds 5 mg/L).

## Verdict

The process is chemically and physically sound at bench scale: PAC-kaolin flocculation of a chain diatom at 1e4 cells/mL in seawater has direct analogues above 80% removal, and magnetite enmeshed in a hydroxide floc and recovered by a magnet is an industrial process with >99% ballast recovery in freshwater and beaker-scale marine analogues. What has never been measured is the combination in seawater with a raster, which is exactly what the MVP measures, so the January headline is a genuine result if the gates hold. Two things should change before freezing: the stock should not be aged and stored in seawater without a week-1 comparison against DI-aged and PAC-first preparation, because the two best sources on seawater PAC-clay say that preparation costs floc size and dose; and the tank protocol should log floor DO/turbidity and attribute recovery misses so raster resuspension is a measured quantity, not a confound. Everything past the tank is not ready, and v4 says so: the field sequence is inconsistent with tidal timing, the benthic benefit has no supporting comparison, dissolved Al from PAC is likely above the marine guideline for hours regardless of retrieval, the forecast trigger wastes about as many doses as it justifies at the test precision, and a student cannot hold the permits for an open-water release. The board sentences are supportable with the two qualifications above.
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

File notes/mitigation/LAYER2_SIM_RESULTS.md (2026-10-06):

# Layer 2 results: simulated bench runs of the treatment loop (2026-09-26; re-run 2026-09-28)

> **2026-10-01:** the plan changed for autonomy reasons: the full loop runs are now aeration and peroxide (seaweed, shellfish and curcumin dropped; `EXECUTION_PLAN.md`, "Plan change 2026-10-01"). The seaweed and shellfish results below are kept as a record.

> **Read the 2026-09-28 re-run first. It supersedes every table further down, which is kept as
> history.** An audit found that the earlier runs did not match the protocol. Every number in the
> re-run section comes from `data/sim/method_summary.csv` and `data/sim/method_design_*.csv`
> (`python src/sim/method_mc.py`, 2,000 draws per method, seed 42).

## Re-run, 2026-09-28: the protocol as planned

**What changed:**
- **Peroxide is a pumped liquid pulse.** The dose is added once per ON day, only when the residual is at
  or below 0.5 mg/L, and decays with the H2O2 half-life. Before, the level was held at the target all
  day, which does not match a single pump pulse.
  - The back-test now uses direct spikes, as in the source (peroxide-03): 1.6 mg/L must cut the
    small-celled alga at least 80% at 24 h, and 0.8 mg/L must stay at or below 60% ("transient"
    inhibition at 0.8 mg/L; 24-h EC50 0.91 mg/L).
  - The fabric-bag release parameters are removed.
- **C_ok** is 50% of the expected untreated peak from the **pilot run**, pulsed on day 7 as in
  PROCEDURES. It was arm A's running peak.
- **H4 floor OFF** as planned: 2 readings in a row below 80% of warm-up, not applied to arm D.
- **The handover** is simulated: forecast arm, rule fires, model silent for 2 days, then the rule
  starts the tank.
- **MAX_ON per method:** peroxide 3 pulses, curcumin 4 pulses, the rest 4 × X.
- **The H1a interval** includes arm A's tank-to-tank spread (Welch t on log peaks). Before, A was
  treated as exact, which made the "95% interval clears 50%" chance too high.
- **Peak cuts** are measured on cell-count-like readings, so curcumin's fluorometer under-reading no
  longer inflates its cut. The loop still sees the biased fluorometer.
- **Nutrients are on the WATER_RECIPE scale:** warm-up about 1, pulse 5-16 µg chl-equivalent, so
  the untreated bloom peaks near 9 µg/L (was 88). If the bench scales the pulse up, scale `n_pulse`
  by the same factor.
- **Doses are the planned ones:** peroxide 0.8 mg/L per pulse, curcumin ladder capped at 2.5,
  shellfish stocked for 2 tank volumes a day with X = 3 d.

**Checks:**
- The controller still matches Layer 1's `run_loop` on 77,958 station-days with 0 mismatches.
- The hourly step matches `solve_ivp` within 0.30%.
- Back-test acceptance: seaweed 34%, bubbles 11%, peroxide 14%, curcumin 49%.

**Results** (n = 3 tanks per arm, forecast trigger with the handover):

| | Seaweed 2 g/L | Shellfish 2 vol/day | Peroxide 0.8 mg/L pulses | Curcumin (cap 2.5) | Bubbles, responsive sp. | Bubbles, unscreened |
|---|---|---|---|---|---|---|
| B peak cut vs A, median [5-95%] | **72%** [52, 84] | **81%** [63, 92] | **74%** [57, 83] | 63% [33, 79] | 25% [9, 48] | 10% [-16, 39] |
| ≥ 50% cut (mean), n = 3 | 97% | 100% | 99% | 78% | 4% | 1% |
| ≥ 50% cut (95% CI incl. A spread), n = 3 / 4 / 5 | 64% / 78% / 84% | 79% / 92% / 96% | 80% / 92% / 95% | 47% / 60% / 65% | 1% / 1% / 1% | 0% / 0% / 0% |
| Reactive C peak cut (starts at 50% of expected peak) | 14% | 22% | 24% | 21% | 6% | 1% |
| C starts after B (median days) | 3.0 | 3.0 | 2.7 | 6.7 | 7.3 | 7.3 |
| B beats C / by 20+ points | 100% / 100% | 100% / 100% | 100% / 100% | 100% / 92% | 99% / 48% | 70% / 22% |
| ON days B / C / D | 12 / 4 / 4 | 24 / 4 / 4 | 11 / 3 / 2 | 23 / 4 / 2 | 30 / 9 / 3 | 30 / 9 / 3 |
| Non-target harm in B | 0% | 0% | 1% | 19% | 0% | 0% |
| False-alarm arm D safe (H2) | 100% | 100% | 100% | 94% | 100% | 100% |
| B ended by the H4 floor | 39% | 93% | 0% | 0% | 0% | 0% |
| Rule trigger instead: peak cut | 55% | 65% | 62% | 50% | 22% | 7% |

**Design sweeps** (400 draws per cell):

| Method | ≥ 50% cut, mean (95%-CI version) | Non-target harm |
|---|---|---|
| **Peroxide, X = 1** | 0.8 mg/L: 99% (80%). 1.6 mg/L: 100% (91%). 3.2 mg/L: 100% (95%) | 0.8: 1%. 1.6: 62%. 3.2: 100% |
| **Curcumin, X = 1** | cap 2.5: 79% (49%). cap 5: 100% (78%) | cap 2.5: 26%. cap 5: 86% |
| **Seaweed, X = 3** | 1 g/L: 55%. 2 g/L: 96% (63%). 3 g/L: 99% (67%) | none |
| **Shellfish, X = 3** | 1 vol/day: 84% (53%). 2 vol/day: 100% (80%) | none |
| **Bubbles** | best 16% (X = 4, 0.6 L/min per L) | none |

**What it means:**
1. **Seaweed, shellfish and peroxide cut the simulated peak by about three-quarters.**
   - Seaweed 72%, shellfish 81%, peroxide 74%. With the honest interval, 3 tanks per arm gives a
     64-80% chance the CI clears 50%; **4 tanks per arm gives 78-92%.**
   - Treating early beats the reactive start in essentially every run.
2. **Peroxide at 0.8 mg/L works through repeated pulses, not one dose.**
   - One 0.8 mg/L dose gives a transient cut (back-test median 48% at 24 h), which is what the source
     paper says.
   - Up to 3 daily 0.8 mg/L pulses cut the simulated peak 74%, with 1% non-target harm. 1.6 mg/L
     harms non-targets in 62% of runs.
   - The screen is restated accordingly (EXECUTION_PLAN S3, PROCEDURES S3).
3. **Curcumin's earlier 92% was inflated** by its fluorometer artefact. Measured on cell-like
   readings it is 63%, and it still harms non-targets in 19% of runs at the 2.5 mg/L cap. It stays a
   comparison screen.
4. **Bubbles still mostly delay the bloom** (25% cut), and B hits MAX_ON in 99% of runs.
5. **The H4 floor matters for shellfish:** the oysters push chlorophyll below 80% of warm-up in 93%
   of runs, so the floor, not the C_ok rule, ends most shellfish episodes. That is the "trim, don't
   remove" rule working as intended, and a bench prediction to check.

**Caveats (in addition to those below):**
- The recipe-scale bloom peaks near 9 µg/L. The pilot run must confirm the fluorometer resolves it.
- The rule-trigger arm is always weaker than the forecast arm with the handover (for example
  seaweed 55% vs 72%).

---

## History: 2026-09-26 runs (superseded by the re-run above)

Scripts:
- `src/sim/tank_model.py`: the tank.
- `src/sim/loop_controller.py`: the ON/OFF loop.
- `src/sim/method_mc.py`: the Monte Carlo.

Parameters are in `src/sim/method_params.csv`, each with source paper ids from `notes/mitigation/scores/`. Outputs are `data/sim/method_summary.csv`, `method_mc_*.csv`, `method_design_*.csv` and `figures/sim/fig_method_*.png`.

**Status:** all five methods simulated (phase 1: seaweed and bubbles; phase 2: peroxide, curcumin and shellfish). The phase 2 summary is at the end.

**What this tests.** Layer 1 replayed the loop on water nobody treated. Layer 2 closes the loop:
- A simulated tank grows a bloom after nutrients go in on day 21.
- The treatment changes the algae, and the controller reacts to noisy daily readings.
- Each of 2,000 draws is a full simulated bench run: arms A (untreated), B (loop), C (late, in these historical runs; now reactive), D (false alarm), n = 3 tanks each, plus 2 spare tanks per arm for a power check.
- The parameters are drawn from the literature ranges and **kept only if they reproduce the paper they came from**:
  - seaweed: 13-47% at 48 h and 74-94% at 72 h (seaweed-03);
  - bubbles: 21-63% over 10 days (mixing-01);
  - both ranges widened by 10 points.

These are predictions to test on the bench, not evidence that a method works.

## Checks passed
- **Integration accuracy:** the hourly exponential step matches scipy's `solve_ivp` within 0.06% over 20 days.
- **Untreated bloom shape:** with mid values, warm-up sits at 1.4 µg/L, the peak is 88 µg/L on day 26, and chlorophyll falls to 12 µg/L by day 55.
- **Controller:** it matches Layer 1's `run_loop` on 77,958 Narragansett station-days with **0 mismatches**.
- **Back-test acceptance:** 34% of seaweed draws and 12% of bubble draws reproduce their calibration paper. The rest are rejected.

## Results (2,000 draws each, forecast trigger, n = 3)

| | Seaweed (kelp 2 g/L, X = 3 d, diatom) | Bubbles, species that responds (0.6 L/min per L, X = 2 d) | Bubbles, species not yet screened |
|---|---|---|---|
| Peak cut, B vs A (median [5-95%]) | **75% [58, 84]** | 20% [5, 41] | 7% [-13, 33] |
| Late arm C peak cut | 0% | 3% | 1% |
| **≥ 50% peak cut (mean), n = 3** | **99%** | 3% | 1% |
| ≥ 50% peak cut (95% CI lower bound), n = 3 / 4 / 5 | **81% / 92% / 95%** | 1% / 1% / 1% | 0% / 1% / 1% |
| B beats late C by 20+ points | 100% | 38% | 15% |
| H1 as written (also fewer ON days than C) | 0% | 0% | 0% |
| ON days: B / C / D | 12 / 4 / 4 | 32 / 9 / 4 | 32 / 9 / 4 |
| False-alarm arm D safe (no pH stop) | 100% | 100% | 100% |
| Rule trigger instead of the forecast: peak cut | 70% | 18% | 7% |

**Design sweep** (400 draws per cell; `fig_method_design_*.png`):

| Method | Result |
|---|---|
| **Seaweed** | The dose matters far more than X. At 2 g/L, X = 2-4 d gives a ≥ 50% cut in 99-100% of runs (CI version 78-85%). At 1 g/L it's only about 50% (CI ~22%); at 0.5 g/L never. |
| **Bubbles** | Best case X = 4 d at 0.6 L/min per L: 11% (median cut 29%). The low rate is slightly worse. |

**What drives the result** (`fig_method_tornado_*.png`):
- **Seaweed:** the diatom's growth rate matters most (faster growth = smaller cut), then the kelp's maximum strength.
- **Bubbles:** the dinoflagellate's growth rate and the late-mortality term.

## What it means
1. **Seaweed is the strongest candidate, if its lab effect carries over to our culture.**
   - At 2 g/L it cuts the simulated peak by about three-quarters, and 3 tanks are nearly always enough (81% chance the CI clears 50%; 92% with 4 tanks).
   - 1 g/L is borderline, so **keep 2 g/L**.
   - X barely matters, so X = 3 d is fine, and X = 2 d is equally good.
2. **Bubbles mostly delay the bloom instead of stopping it.**
   - The calibrated effect is a partial pause in division (a growth multiplier around 0.83), so the bloom peaks about 8 days later and about 20% lower (see `fig_method_curves.png`).
   - The loop can't switch off because chlorophyll never falls below C_ok, so B stays ON for about 32 days.
   - A ≥ 50% cut is unlikely (3%) even with a responsive species.
   - Bubbles look like the weaker full-run candidate. The second full run should probably go to shellfish (to be simulated next), with bubbles kept as a short screen.
3. **H1 as written can't pass for either method.**
   - Late treatment (arm C) starts after the peak, when the bloom is already crashing, so it is short (about 4 days) and does almost nothing (0-3% cut).
   - "B uses less treatment than C" therefore fails even when B works.
   - **Suggested wording for LOOP_PREREG.md** (the student's decision): H1a, a ≥ 50% peak cut vs A, and H1b, B's cut beats C's.
   - Reporting treatment per percent of peak cut is also more meaningful than raw ON days.
4. **The forecast trigger helps a little over the simple rule** (75% vs 70% for seaweed).
5. **Seaweed's pH safety limit wasn't reached at 2 g/L,** using the levelling-off pH rise that matches Sylvers & Gobler's 8.1-8.9. A linear pH rise, used in an earlier draft, made pH the dominant risk. Measuring pH on the bench matters for this reason.

## Caveats
- **Transfer from the calibration papers:** the seaweed result inherits the lab effect of Sylvers & Gobler on *Pseudo-nitzschia*. Two full-text records show the effect shrinking in field water (seaweed-12: over 97% in the lab vs 13-44% in field water) and species-specific responses. Our *Phaeodactylum* or *Thalassiosira* may respond less, which is why the seaweed screen comes first.
- **Model simplifications:**
  - one algal population, well mixed;
  - no nutrient uptake by the seaweed and no bacteria;
  - chlorophyll stands in for cell counts;
  - the forecast is an emulator (a persistence projection with noise), not the Narragansett model.
- **Bubble parameters** come mostly from shaker and shear studies. Only Sung & Gobler used bubbles.
- **The "B beats C by 20 points" margin** is our choice, not pre-registered.

## Phase 2: peroxide, curcumin, shellfish (2,000 draws each, forecast trigger, n = 3)

**Calibration (back-tests):**
- **Peroxide:** a single 1.6 mg/L bag on a small-celled alga must cut it ≥ 80% in 24 h (peroxide-03: > 90%, EC50 0.91 mg/L). 87% of draws accepted.
- **Curcumin:** 5 mg/L → 22-99% at 24 h, 3 mg/L → 20-70%, 1 mg/L → no effect (curcumin-01, and curcumin-02's 2022 and 2024 runs). 48% of draws accepted.
- **Shellfish:** no single calibration experiment, so all draws are used. The biggest unknown is how much of the planned clearance the animals actually deliver (20-120%, since lab maxima overestimate by up to 10×; shellfish-04, -07, -12).

**Non-target harm** = the highest peroxide or curcumin level in a tank passes a harm threshold drawn from the literature:
- peroxide 0.86-3 mg/L (krill 48-h LC50 0.86; *Moina* no-effect 1.5; *Daphnia* no-effect 3);
- curcumin 1.8-6 mg/L (zebrafish larval LD50 1.8-2.8; no harm to adult clams, crabs or urchins at 5 mg/L).

| | Peroxide bag, 1.6 mg/L (small-celled alga) | Curcumin ladder 1 → 2.5 → 5 mg/L (dinoflagellate) | Shellfish, 1 tank volume/day (diatom) |
|---|---|---|---|
| Peak cut, B vs A (median [5-95%]) | **95% [91, 98]** | **92% [78, 96]** | 31% [10, 61] |
| ≥ 50% cut (mean / 95% CI), n = 3 | 100% / 100% | 100% / 98% | 16% / 5% |
| B beats late C by 20+ points | 100% | 99% | 76% |
| ON days: B / C / D | 19 / 2 / 2 | 19 / 4 / 3 | 19 / 5 / 2 |
| **Non-target harm in B tanks** | **38%** | **91%** | 0% |
| False-alarm arm D safe | 67% | 87% | 100% |

**Design sweeps** (400 draws per cell):

| Method | Result |
|---|---|
| **Peroxide** | **0.8 mg/L** still gives a ≥ 50% cut in 100% of runs (CI version 89-99%) with **0% non-target harm**. 1.6 mg/L harms in about 36% of runs; 3.2 mg/L harms in 98% and hits the 2.8 mg/L pull limit in 78%. |
| **Curcumin** | Capping the ladder at **2.5 mg/L** keeps 76-94% of runs passing (more with a longer X) and cuts harm to about 26%. A 5 mg/L cap harms in about 90%. |
| **Shellfish** | The stocking decides it. At 1 volume/day only 19-46% pass; at **2 volumes/day** with X = 3-4 d, 94-95% (CI version 67-79%). The biggest unknown is the real clearance vs planned (Spearman +0.75), which the 4-hour clearance test measures directly. |

## What the full set means
1. **Seaweed stays the lead full run.** It gives a large cut, no non-target harm, and it's retrievable.
2. **Shellfish is the better second full run, not bubbles, if the animals are stocked for 2 tank volumes per day.**
   - The 4-hour clearance test must come first: it measures the number that decides success.
   - Bubbles mostly delay the bloom.
3. **Peroxide works only on small cells, and the dose matters for safety.**
   - Lower the target from 1.6 to **0.8 mg/L**: the simulated cut is the same and the non-target harm disappears.
   - It stays a short screen on a small-celled alga, as planned.
4. **Curcumin cuts strongly but mostly at doses that harm other organisms.** It's a comparison screen only; if it's run at all, cap the ladder at 2.5 mg/L and run the brine shrimp check in light.
5. **In every method, the late arm C does almost nothing (0-4%).** That confirms the timing claim the loop rests on: acting early matters.

**Planned changes to the method files (not applied yet):**
- `03_PEROXIDE_BAG.md`: target 1.6 → 0.8 mg/L.
- `05_SHELLFISH.md`: stock for 2 tank volumes per day, X = 3-4 d.
- `04_CURCUMIN.md`: ladder cap 5 → 2.5 mg/L.
- `EXECUTION_PLAN.md`: second full run = shellfish.

**Added caveats:**
- **Peroxide:** the model follows one small-celled population, so it can't show the cell-size selectivity the screen tests.
- **Curcumin:** its fluorometer artefact (0-30% under-reading) can make the loop think chlorophyll fell; the bench uses cell counts for this reason.
- **Shellfish:**
  - the model has no pseudofaeces and no toxin;
  - regrowth is fed by excreted ammonia;
  - "clearance" stands in for all of the animals' behaviour.
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

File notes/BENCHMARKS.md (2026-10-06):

> **2026-09-28 audit:** LIS numbers in this file that are not marked as re-run predate the audit; current values are in `notes/S1_NUMBERS_SHEET.md` (21-day station-day: POD 0.791, precision 0.125, lift 1.63 at t*=0.20; basin 1.75x). The Narragansett refit/transfer claims are being re-checked in the fork.

# Benchmarks: LIS EWS vs Reference HAB Forecast Systems

Task 3 of the August 2026 plan. Status (2026-09-18): benchmark table, positioning
table and operational-products comparison are complete and sourced to primary
documents. The C-HARM POD/FAR item is **done** — pulled from the Anderson et al.
2016 NOAA IR manuscript. Two items remain genuinely open: the Florida HAB-OFS
(CO-OPS 073) numbers and where the table sits in the paper. See Open Items.

## Why this comparison is framed in POD / FAR / CSI

These are the standard categorical verification metrics for operational
hazard forecasts (NOAA HAB-OFS, NWS severe weather). Using them makes the
LIS system directly comparable to the reference systems below and avoids
inventing a private vocabulary. Definitions: POD = TP/(TP+FN),
FAR = FP/(TP+FP), CSI = TP/(TP+FP+FN).

## Key precedent: assessable-only verification is standard practice

The NOAA Gulf of Mexico HAB Operational Forecast System skill assessment
for Texas (Kavanaugh et al. 2015, NOAA Technical Report NOS CO-OPS 080)
could assess only a small fraction of issued forecasts, because
validation required field observations that often did not exist along
sparsely monitored coastline:

- Transport direction: 9 of 187 issued forecasts assessable (4.8%)
- Transport distance: 5 of 208 assessable (2.4%)
- Respiratory irritation: 0.9-8.9% assessable depending on bloom year

Forecasts without observational evidence were recorded as "unconfirmed"
and EXCLUDED from skill statistics, not counted as wrong. The Florida
assessment (Kavanaugh et al. 2013) similarly ranged 10-54% assessable.

This is the same convention as our verifiable-window FAR (ver_far):
score alerts only where a verification observation exists within the
horizon. In our test era, 41% of station-day windows contain zero
observations; the cadence-thinning experiment shows all-window FAR
degrades with sampling sparsity while verifiable-window FAR is flat
(~0.8), decomposing alert error into a cadence-driven component and a
cadence-invariant (biological) residual.
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

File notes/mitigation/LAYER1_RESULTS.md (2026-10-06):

# Layer 1 results: the control loop replayed on real history (2026-09-24)

Script: `src/models/control_loop_sim.py`. Outputs: `data/control_loop_sim.csv`,
`data/control_loop_episodes.csv`. The rules were copied unchanged from `00_CONTROL_LOOP.md`,
which was written before this was run.

**What this tests:** the *control logic* only (when the loop would switch on, whether that was
before a real bloom, and how much treatment time it would use). The water in these records was
never treated, so it **cannot** show whether bubbles or seaweed work. That's Layers 2-3.
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

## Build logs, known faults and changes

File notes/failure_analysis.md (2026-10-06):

> **SUPERSEDED.** Marked 2026-08-30. Built on the **XGBoost** model with a 7-day label,
> evaluated on 2020-2022 as validation. Its raw counts (10,232 FP / 4,904 FN) are on the
> un-aggregated multi-cast row scale that `KEY_NUMBERS.md` Section 6 bans — the correct
> scale is 11,447 station-days. The qualitative patterns (errors peak Jul-Aug; western
> stations A4, B3, D3, C1, C2, F3 dominate) still hold and are corroborated elsewhere,
> but **no number in this file should be quoted.**

# Failure Analysis Memo

## Overview
XGBoost model evaluated on held-out 2020-2022 validation data.
- False positives: 10,232 (predicted bloom, no bloom occurred)
- False negatives: 4,904 (missed bloom events)
- FP:FN ratio of ~2:1 -- model is conservative, more likely to over-predict than miss

## Temporal Patterns
Both false positives and false negatives peak in July-August:
- FP: July 2,581 / August 3,807
- FN: July 1,391 / August 1,848

Summer is the hardest season. High temperatures and elevated background 
chlorophyll create ambiguous conditions where the model struggles to 
distinguish true bloom trajectories from seasonal elevation.

## Geographic Patterns
Top error stations are all western LIS (A4, B3, D3, C1, C2, F3):
- Station A4 leads in both FP (616) and FN (311)
- Western Narrows stations account for disproportionate share of errors

This is consistent with Perreira (2021) who showed A4 is underrepresented 
in the standard CT DEEP monitoring estimate and has the highest and most 
variable chlorophyll concentrations in the Sound.

## Hypotheses
1. Summer ambiguity: the 7-day rolling chlorophyll signal is less 
   discriminative in summer when background CHL is elevated
2. Western LIS complexity: A4 and Narrows stations experience rapid, 
   localized bloom dynamics driven by East River nutrient inputs that 
   are harder to predict from lagged features alone
3. The LSTM's temporal modeling may reduce summer errors by capturing 
   the full trajectory shape rather than just the rolling mean

## Implication for Model Development
- Consider separate summer/non-summer models or seasonal threshold adjustment
- ConvLSTM spatial model may better capture western LIS bloom dynamics
- Additional features capturing East River discharge or NYC WWTP nutrient 
  outputs could improve western station predictions

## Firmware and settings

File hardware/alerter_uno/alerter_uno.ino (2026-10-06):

/*
  alerter_uno.ino -- the forecast-triggered ON/OFF loop on an Arduino Uno (one tank)
  ==================================================================================
  Same rules as src/sim/loop_controller.py (Controller.step, n = 1) and
  notes/mitigation/00_CONTROL_LOOP.md:

    not ON:  start if the trigger fires today; next check = today + X; remember today's chl.
    ON:      on a check day with no reading, check again tomorrow;
             OFF if  p < T_off (= 0.8 T_on)  AND  chl < C_ok  AND  chl <= chl at the last check;
             else STOP if ON for >= MAX_ON (= 4 X, or `maxon`) days; else next check = today + X.
             FLOOR: 2 readings in a row below floor x warm-up mean while ON -> OFF (H4).
    The OFF day itself counts as ON; the tank can restart the next day.

  Triggers:  mode F (forecast)  p >= T_on
             mode R (rule)      chl rose 2 calendar days in a row AND chl > 2 x warm-up mean
             mode H (handover)  forecast, but if the rule fires and the forecast has not started
                                the tank 2 days later, the rule starts it (00_CONTROL_LOOP.md)

  Input, one line per day in the Serial Monitor (115200 baud, "Newline"):
      <day> <p> <chl>          e.g.  12 0.63 7.4      (use - for a missing value)
  Loop commands:
      x <days>   cok <ug/L>   ton <p>   mode F|R|H   warm <mean chl>
      floor <frac>   floor OFF level as a share of warm (default 0.8; 0 = off, e.g. arm D)
      maxon <days>   MAX_ON in days since START (0 = 4 x X; peroxide 3 with x 1)
      pulse <s>  dosing-pump mode (peroxide): while ON, the relay runs for <s> seconds at START
                 and at each check day that continues the episode, then switches off; the state
                 still prints ON. 0 (default) = relay held ON for the whole episode (air pump)
      skip       skip the next pulse (e.g. H2O2 residual > 0.5 mg/L at the check)
      flush <s>  (USE_DOSER) seconds the circulation pump keeps running after a pulse (default 90)
  Dosing module (USE_DOSER 1, added 2026-10-03; README "Dosing module"): each pulse runs
      PRIME (circulation pump D12 only, 5 s) -> DOSE (circulation + dosing pump D10, <pulse> s)
      -> FLUSH (circulation only, <flush> s) -> IDLE.
      No flow (D8 HIGH) at the end of PRIME, or for > 0.5 s during DOSE -> both pumps stop,
      "DOSE_ABORT no_flow", beep, warning LED; later pulses print pulse=aborted until `pulse <s>`
      is sent again (after the intake is fixed) or `reset`.
      Reservoir float (D4 LOW) -> "REFILL" once and the warning LED; dosing is still allowed.
      temp <lo> <hi> temperature warning window, C (default 10 17)
      servo <on> <off>   servo angles for ON / OFF (USE_SERVO)
      stop       (safety stop: OFF at the next daily line, e.g. DO kit < 4 mg/L)
      mute 0|1   (silence the buzzer; alerter_link.py uses it to replay history after a reset)
      status     reset
  Sensor commands (each sensor is off until its USE_ flag below is 1):
      read       one line "S temp=.. ph=.. ph_v=.. fl=.. chl=.."  (nan = sensor off / not calibrated)
      every <min>   print that line every <min> minutes (0 = off; default 10)
      cal686     pH probe in pH 6.86 buffer: store its voltage     cal918   same for pH 9.18
      blank      fluorometer: cuvette of plain seawater, store its signal as zero chlorophyll
      chlk <k>   fluorometer: ug/L of chlorophyll per signal count (from the dilution series)
      gain l|m|h|x   fluorometer sensitivity (TSL2591 gain: low, medium, high, max); saved with the
                     calibration, because blank and chlk are only valid at the gain they were set at
      cal        show the stored calibration        calclear   erase it
      Calibration is kept in EEPROM, so it survives resets and uploads.

  Outputs:  green LED = idle, blue LED = treatment ON, relay = ON (or the timed pulse, `pulse`),
            white LED = warning (safety stop, temperature out of range, missed reading),
            buzzer: 3 beeps = ON, 1 long = OFF, fast beeps = temperature alarm.

  Wiring: hardware/alerter_uno/README.md.
*/
#include <math.h>
#include <EEPROM.h>

// ---- sensors: set to 1 once the part is wired (libraries: Arduino IDE -> Library Manager)
#ifndef USE_DS18B20
#define USE_DS18B20 1   // temperature probe            needs OneWire + DallasTemperature
#endif
#ifndef USE_TSL2591
#define USE_TSL2591 1   // chlorophyll (fluorometer)    needs Adafruit TSL2591 Library + Adafruit Unified Sensor
#endif
#ifndef USE_PH
#define USE_PH 1        // pH module (analog)           no library
#endif
#ifndef USE_DOSER
#define USE_DOSER 0     // inline-dilution dosing module: circulation relay D12, flow D8, float D4
#endif
#ifndef USE_SERVO
#define USE_SERVO 0     // spare servo on D11 (planned: fluorometer wiper / reference target; not built)
#endif

#if USE_DS18B20
#include <OneWire.h>
#include <DallasTemperature.h>
#endif
#if USE_SERVO
#include <Servo.h>      // uses Timer1: pins 9 and 10 lose PWM, which is fine (digitalWrite only)
#endif
#if USE_TSL2591
#include <Wire.h>
#include <Adafruit_Sensor.h>
#include <Adafruit_TSL2591.h>
#endif

// Pins match the circuito.io wiring diagram (hardware/alerter_uno/README.md)
// (circuito's yellow LED = our white warning LED; the relay is not in the circuito picture, it goes on D10)
const int PIN_GREEN = 6, PIN_YELLOW = 9, PIN_RED = 5, PIN_BUZZ = 2, PIN_RELAY = 10, PIN_TEMP = 3;
const int PIN_FLUOR_LED = 7;   // fluorometer's blue excitation LED (TSL2591 itself is on SDA/SCL)
const int PIN_PH = A2;         // pH module Po (A4/A5 are taken by SDA/SCL)
const int PIN_SERVO = 11;      // servo signal (USE_SERVO)
#if USE_DOSER
const int PIN_CIRC = 12;       // relay channel 2: circulation pump (D10 = dosing pump)
const int PIN_FLOW = 8;        // flow switch to GND, INPUT_PULLUP: LOW = water flowing
const int PIN_LEVEL = 4;       // reservoir float switch to GND, INPUT_PULLUP: LOW = reservoir low
const unsigned long PRIME_MS = 5000, NOFLOW_GRACE_MS = 500;
#endif
const bool RELAY_ACTIVE_LOW = false;  // false: bare relay via transistor, or LED stand-in; true for most opto relay modules
float tempLo = 10.0, tempHi = 17.0;   // planned run 12-15 C (WATER_RECIPE.md), +/- 2 C; `temp` changes it
const int FLOOR_DAYS = 2, HANDOVER_DAYS = 2;

float tOn = 0.50, cOk = 5.0, warmMean = NAN, floorFrac = 0.8;
int X = 3, maxOnDays = 0;      // 0 = 4 x X
char mode = 'F';
int servoOnDeg = 90, servoOffDeg = 0;

bool on = false, warn = false, tempAlarm = false, muted = false;
long startDay = 0, checkDay = 0;
float lastChl = NAN, chlHist[3] = {NAN, NAN, NAN};
long histDay = -100000;        // calendar day of chlHist[2]
long pendingDay = -1;          // handover: day the rule fired while idle (-1 = none)
int episodes = 0, belowCount = 0;
bool safetyStop = false;
unsigned int pulseSec = 0;     // 0 = relay held for the whole ON episode
bool skipNext = false, pumpOn = false;
unsigned long pumpStartMs = 0;
#if USE_DOSER
enum DoseState : byte { D_IDLE, D_PRIME, D_DOSE, D_FLUSH };
DoseState dState = D_IDLE;
unsigned int flushSec = 90;
unsigned long dStartMs = 0, noFlowMs = 0;
bool doseFault = false, refillShown = false;
#endif

#if USE_DS18B20
OneWire oneWire(PIN_TEMP);
DallasTemperature sensors(&oneWire);
#endif
#if USE_TSL2591
Adafruit_TSL2591 tsl = Adafruit_TSL2591(2591);
bool tslOk = false;
#endif
float tempC = NAN;

#if USE_SERVO
Servo servo;
#endif

// ---- calibration kept in EEPROM (gain added 2026-09-28; the old 0xA1E7 layout is migrated)
struct CalV1 { uint16_t magic; float v686, v918, blank, chlK; };
struct Cal { uint16_t magic; float v686, v918, blank, chlK; char gain; };
const uint16_t CAL_MAGIC_V1 = 0xA1E7, CAL_MAGIC = 0xA1E8;
Cal cal = {CAL_MAGIC, NAN, NAN, NAN, NAN, 'm'};
unsigned int everyMin = 10;

const int BUZZ_HZ = 2000;   // passive buzzer: needs a tone, not a steady HIGH

void beep(int ms, int n, int gap) {
  if (muted) return;                      // the laptop link replays history muted
  for (int i = 0; i < n; i++) {
    tone(PIN_BUZZ, BUZZ_HZ); delay(ms);
    noTone(PIN_BUZZ);        delay(gap);
  }
}

void setOutputs() {
  digitalWrite(PIN_GREEN, on ? LOW : HIGH);
  digitalWrite(PIN_RED, on ? HIGH : LOW);
  digitalWrite(PIN_YELLOW, (warn || tempAlarm) ? HIGH : LOW);
#if USE_DOSER
  bool relay = pulseSec > 0 ? (dState == D_DOSE) : on;
  bool circ = dState != D_IDLE;
  digitalWrite(PIN_CIRC, (circ != RELAY_ACTIVE_LOW) ? HIGH : LOW);
#else
  bool relay = pulseSec > 0 ? (on && pumpOn) : on;
#endif
  digitalWrite(PIN_RELAY, (relay != RELAY_ACTIVE_LOW) ? HIGH : LOW);
#if USE_SERVO
  servo.write(on ? servoOnDeg : servoOffDeg);
#endif
}

#if USE_DOSER
void doserTo(DoseState st) {
  dState = st; dStartMs = millis(); noFlowMs = 0;
  setOutputs();
  Serial.println(st == D_PRIME ? F("DOSER prime") : st == D_DOSE ? F("DOSER dose") :
                 st == D_FLUSH ? F("DOSER flush") : F("DOSER idle"));
}

void doseAbort() {
  dState = D_IDLE; doseFault = true; warn = true;
  setOutputs();
  Serial.println(F("DOSE_ABORT no_flow"));
  beep(400, 3, 150);
}

void doserTick() {                          // called from loop(): advances PRIME -> DOSE -> FLUSH -> IDLE
  unsigned long t = millis() - dStartMs;
  bool flow = digitalRead(PIN_FLOW) == LOW;
  if (dState == D_PRIME && t >= PRIME_MS) { if (flow) doserTo(D_DOSE); else doseAbort(); }
  else if (dState == D_DOSE) {
    if (flow) noFlowMs = 0;
    else if (noFlowMs == 0) noFlowMs = millis() | 1;
    if (noFlowMs && millis() - noFlowMs >= NOFLOW_GRACE_MS) doseAbort();
    else if (t >= pulseSec * 1000UL) doserTo(D_FLUSH);
  }
  else if (dState == D_FLUSH && t >= flushSec * 1000UL) doserTo(D_IDLE);
}
#endif

void pushHist(float v) { chlHist[0] = chlHist[1]; chlHist[1] = chlHist[2]; chlHist[2] = v; }

bool ruleTrigger() {
  // chlHist = [day-2, day-1, today] by CALENDAR day (a skipped day is NaN)
  return !isnan(chlHist[0]) && !isnan(chlHist[1]) && !isnan(chlHist[2]) && !isnan(warmMean)
      && chlHist[1] > chlHist[0] && chlHist[2] > chlHist[1] && chlHist[2] > 2 * warmMean;
}

void stepDay(long day, float p, float chl) {
  for (long g = histDay + 1; g < day && g < histDay + 4; g++) pushHist(NAN);   // skipped days
  pushHist(chl);
  histDay = day;
  bool rule = ruleTrigger();
  bool fc = !isnan(p) && p >= tOn;
  bool trig = (mode == 'R') ? rule : fc;
  float tOff = 0.8 * tOn;
  int maxOn = maxOnDays > 0 ? maxOnDays : 4 * X;

  bool was = on, ended = false, maxed = false, recheck = false;
  warn = false;
  if (was && day >= checkDay) {
    if (isnan(chl)) {
      checkDay = day + 1;
      warn = true;                                    // re-measure day with no reading
    } else {
      bool notRising = isnan(lastChl) || chl <= lastChl;
      bool stopOk = !isnan(p) && p < tOff && chl < cOk && notRising;
      maxed = !stopOk && (day - startDay >= maxOn);
      if (!stopOk && !maxed) { lastChl = chl; checkDay = day + X; recheck = true; }
      ended = stopOk || maxed;
    }
  }
  if (was && safetyStop) { ended = true; warn = true; }
  safetyStop = false;
  // floor rule (H4): FLOOR_DAYS readings in a row below floorFrac x warm-up mean while ON
  bool floorHit = false;
  if (was && !isnan(chl)) {
    if (floorFrac > 0 && !isnan(warmMean) && chl < floorFrac * warmMean) belowCount++;
    else belowCount = 0;
  }
  if (was && !ended && belowCount >= FLOOR_DAYS) { ended = true; floorHit = true; }
  on = was && !ended;
  if (!on) belowCount = 0;
  // handover (mode H): rule fired while idle, forecast silent HANDOVER_DAYS later -> start
  if (mode == 'H') {
    if (ended) pendingDay = -1;
    if (!was && rule && pendingDay < 0) pendingDay = day;
    if (!was && pendingDay >= 0 && day - pendingDay >= HANDOVER_DAYS) trig = true;
  }
  bool started = false;
  if (!was && trig) {
    on = true; started = true; pendingDay = -1;
    startDay = day; checkDay = day + X; lastChl = chl; episodes++;
  }
  // pulse mode: one timed pump run at START and at each check day that continues the episode
  bool dose = pulseSec > 0 && (started || (on && recheck));
  bool skipped = dose && skipNext;
  if (dose) skipNext = false;
#if USE_DOSER
  bool aborted = dose && !skipped && doseFault;
  if (aborted) warn = true;                   // a no-flow abort blocks dosing until `pulse <s>` re-arms it
#else
  if (!on) pumpOn = false;
  if (dose && !skipped) { pumpOn = true; pumpStartMs = millis(); }
#endif
  setOutputs();
  if (started) beep(120, 3, 120);
  else if (was && ended) beep(800, 1, 0);

  Serial.print(F("day=")); Serial.print(day);
  Serial.print(F(" p=")); Serial.print(p, 2);
  Serial.print(F(" chl=")); Serial.print(chl, 2);
  Serial.print(F(" -> "));
  if (started) Serial.print(F("START"));
  else if (was && ended) Serial.print(maxed ? F("STOP_MAX_ON") : floorHit ? F("OFF_FLOOR") : F("OFF"));
  else Serial.print(on ? F("ON") : F("idle"));
  if (on) { Serial.print(F(" next_check=")); Serial.print(checkDay); }
  Serial.print(F(" episodes=")); Serial.print(episodes);
  if (dose) {
    Serial.print(F(" pulse="));
    if (skipped) Serial.print(F("skipped"));
#if USE_DOSER
    else if (aborted) Serial.print(F("aborted"));
#endif
    else { Serial.print(pulseSec); Serial.print('s'); }
  }
  Serial.println();
#if USE_DOSER                                 // after the day line, so the link sees it first
  if (!on && (dState == D_PRIME || dState == D_DOSE)) doserTo(D_FLUSH);
  if (dose && !skipped && !aborted) doserTo(D_PRIME);
#endif
}

// ------------------------------------------------------------------ sensors
void readTemp() {
#if USE_DS18B20
  sensors.requestTemperatures();
  float t = sensors.getTempCByIndex(0);
  tempC = (t > -100) ? t : NAN;          // -127 = probe not found
#endif
}

float readPhVolts() {
#if USE_PH
  long s = 0;
  for (int i = 0; i < 40; i++) { s += analogRead(PIN_PH); delay(3); }
  // Assumes a 5.000 V ADC reference. USB supplies 4.7-5.1 V, which shifts every reading; the
  // two-point buffer calibration absorbs a fixed offset, so re-run cal686/cal918 whenever the
  // power source changes (and power the Uno from the same supply during a run).
  return s / 40.0 * 5.0 / 1023.0;
#else
  return NAN;
#endif
}

float phFromVolts(float v) {
  if (isnan(v) || isnan(cal.v686) || isnan(cal.v918) || fabs(cal.v918 - cal.v686) < 0.01) return NAN;
  return 6.86 + (v - cal.v686) * (9.18 - 6.86) / (cal.v918 - cal.v686);
}

float readFluor() {
  // Blue LED off, then on; the difference is the light the LED causes (chlorophyll glow
  // through the red filter). Ambient light and sensor offset cancel out.
#if USE_TSL2591
  if (!tslOk) return NAN;
  float dark = 0, lit = 0;
  digitalWrite(PIN_FLUOR_LED, LOW);
  for (int i = 0; i < 3; i++) dark += tsl.getFullLuminosity() & 0xFFFF;
  digitalWrite(PIN_FLUOR_LED, HIGH);
  delay(20);
  for (int i = 0; i < 3; i++) {
    uint16_t full = tsl.getFullLuminosity() & 0xFFFF;
    if (full == 0xFFFF) { digitalWrite(PIN_FLUOR_LED, LOW); Serial.println(F("fluor: SATURATED, lower the gain")); return NAN; }
    lit += full;
  }
  digitalWrite(PIN_FLUOR_LED, LOW);
  return (lit - dark) / 3.0;
#else
  return NAN;
#endif
}

float chlFromFluor(float f) {
  if (isnan(f) || isnan(cal.blank) || isnan(cal.chlK)) return NAN;
  return (f - cal.blank) * cal.chlK;
}

void printSensors() {
  readTemp();
  float v = readPhVolts(), fl = readFluor();
  Serial.print(F("S temp=")); Serial.print(tempC, 2);
  Serial.print(F(" ph=")); Serial.print(phFromVolts(v), 2);
  Serial.print(F(" ph_v=")); Serial.print(v, 3);
  Serial.print(F(" fl=")); Serial.print(fl, 1);
  Serial.print(F(" chl=")); Serial.println(chlFromFluor(fl), 2);
}

void printCal() {
  Serial.print(F("cal v686=")); Serial.print(cal.v686, 3);
  Serial.print(F(" v918=")); Serial.print(cal.v918, 3);
  Serial.print(F(" blank=")); Serial.print(cal.blank, 1);
  Serial.print(F(" chlk=")); Serial.print(cal.chlK, 5);
  Serial.print(F(" gain=")); Serial.println(cal.gain);
}

void saveCal() { EEPROM.put(0, cal); printCal(); }

void setGain(char g) {
#if USE_TSL2591
  if (!tslOk) { Serial.println(F("fluor: TSL2591 not found")); return; }
  tsl2591Gain_t gain = g == 'l' ? TSL2591_GAIN_LOW : g == 'h' ? TSL2591_GAIN_HIGH : g == 'x' ? TSL2591_GAIN_MAX : TSL2591_GAIN_MED;
  tsl.setGain(gain);
  Serial.print(F("gain=")); Serial.println(g);
  if (cal.gain != g) {           // blank and chlk belong to one gain: store it with them
    cal.gain = g;
    Serial.println(F("gain changed: redo `blank` and `chlk` at this gain"));
    saveCal();
  }
#else
  (void)g;
  Serial.println(F("fluor: USE_TSL2591 is 0"));
#endif
}

// ------------------------------------------------------------------ commands
float parseVal(const char *s) {
  if (s == NULL || s[0] == '\0' || (s[0] == '-' && s[1] == '\0') || s[0] == 'n' || s[0] == 'N') return NAN;
  return atof(s);
}

void printStatus() {
  Serial.print(F("mode=")); Serial.print(mode);
  Serial.print(F(" X=")); Serial.print(X);
  Serial.print(F(" T_on=")); Serial.print(tOn, 2);
  Serial.print(F(" T_off=")); Serial.print(0.8 * tOn, 2);
  Serial.print(F(" C_ok=")); Serial.print(cOk, 2);
  Serial.print(F(" MAX_ON=")); Serial.print(maxOnDays > 0 ? maxOnDays : 4 * X);
  Serial.print(F(" warm=")); Serial.print(warmMean, 2);
  Serial.print(F(" floor=")); Serial.print(floorFrac, 2);
  Serial.print(F(" temp_win=")); Serial.print(tempLo, 1); Serial.print(F("-")); Serial.print(tempHi, 1);
  if (pulseSec > 0) { Serial.print(F(" pulse=")); Serial.print(pulseSec); Serial.print(skipNext ? F("s(skip next)") : F("s")); }
#if USE_DOSER
  Serial.print(F(" flush=")); Serial.print(flushSec);
  Serial.print(F(" circ=")); Serial.print(dState != D_IDLE ? F("on") : F("off"));
  Serial.print(F(" flow=")); Serial.print(digitalRead(PIN_FLOW) == LOW ? F("yes") : F("no"));
  Serial.print(F(" level=")); Serial.print(digitalRead(PIN_LEVEL) == LOW ? F("LOW") : F("ok"));
  if (doseFault) Serial.print(F(" dose=FAULT"));
#endif
  Serial.print(F(" state=")); Serial.print(on ? F("ON") : F("idle"));
  Serial.print(F(" temp=")); Serial.println(tempC, 1);
}

void handleLine(char *line) {
  char *a = strtok(line, " \t\r");
  if (!a) return;
  char *b = strtok(NULL, " \t\r");
  char *c = strtok(NULL, " \t\r");
  if (isdigit(a[0])) { stepDay(atol(a), parseVal(b), parseVal(c)); return; }
  if (!strcmp(a, "read"))           { printSensors(); return; }
  if (!strcmp(a, "every") && b)     { everyMin = atoi(b); Serial.print(F("every=")); Serial.println(everyMin); return; }
  if (!strcmp(a, "cal686"))         { cal.v686 = readPhVolts(); saveCal(); return; }
  if (!strcmp(a, "cal918"))         { cal.v918 = readPhVolts(); saveCal(); return; }
  if (!strcmp(a, "blank"))          { cal.blank = readFluor(); saveCal(); return; }
  if (!strcmp(a, "chlk") && b)      { cal.chlK = atof(b); saveCal(); return; }
  if (!strcmp(a, "gain") && b)      { setGain(tolower(b[0])); return; }
  if (!strcmp(a, "cal"))            { printCal(); return; }
  if (!strcmp(a, "calclear"))       { cal = {CAL_MAGIC, NAN, NAN, NAN, NAN, 'm'}; saveCal(); return; }
  if (!strcmp(a, "x") && b)         X = max(1, atoi(b));
  else if (!strcmp(a, "cok") && b)  cOk = atof(b);
  else if (!strcmp(a, "ton") && b)  tOn = atof(b);
  else if (!strcmp(a, "mode") && b) { char m = toupper(b[0]); mode = (m == 'R' || m == 'H') ? m : 'F'; }
  else if (!strcmp(a, "warm") && b) warmMean = atof(b);
  else if (!strcmp(a, "floor") && b) floorFrac = atof(b);
  else if (!strcmp(a, "maxon") && b) maxOnDays = max(0, atoi(b));
  else if (!strcmp(a, "pulse") && b) { pulseSec = max(0, atoi(b)); pumpOn = false;
#if USE_DOSER
                                      doseFault = false; if (dState != D_IDLE) doserTo(D_IDLE);
#endif
                                      setOutputs(); }
#if USE_DOSER
  else if (!strcmp(a, "flush") && b) flushSec = max(0, atoi(b));
#endif
  else if (!strcmp(a, "skip"))      skipNext = true;
  else if (!strcmp(a, "temp") && b && c) { tempLo = atof(b); tempHi = atof(c); }
  else if (!strcmp(a, "servo") && b && c) { servoOnDeg = constrain(atoi(b), 0, 180); servoOffDeg = constrain(atoi(c), 0, 180); setOutputs(); }
  else if (!strcmp(a, "stop"))      { safetyStop = true; Serial.println(F("safety stop at the next daily line")); return; }
  else if (!strcmp(a, "mute") && b) muted = atoi(b) != 0;
  else if (!strcmp(a, "reset"))     { on = false; warn = false; episodes = 0; lastChl = NAN; belowCount = 0; pendingDay = -1;
                                      pumpOn = false; skipNext = false;
#if USE_DOSER
                                      doseFault = false; dState = D_IDLE;
#endif
                                      histDay = -100000; for (int i = 0; i < 3; i++) chlHist[i] = NAN; setOutputs(); }
  else if (strcmp(a, "status"))     { Serial.println(F("? unknown command")); return; }
  printStatus();
  (void)c;
}
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
void loop() {
#if USE_DOSER
  doserTick();
  if (millis() - lastLevelMs > 10000) {      // reservoir float: REFILL once per low event
    lastLevelMs = millis();
    if (digitalRead(PIN_LEVEL) == LOW) {
      if (!refillShown) { Serial.println(F("REFILL")); refillShown = true; }
      if (!warn) { warn = true; setOutputs(); }
    } else refillShown = false;
  }
#else
  if (pumpOn && millis() - pumpStartMs >= pulseSec * 1000UL) { pumpOn = false; setOutputs(); }
#endif
  while (Serial.available()) {
    char ch = Serial.read();
    if (ch == '\n') { buf[len] = '\0'; handleLine(buf); len = 0; }
    else if (len < sizeof(buf) - 1) buf[len++] = ch;
  }
#if USE_DS18B20
  if (millis() - lastTempMs > 10000) {
    lastTempMs = millis();
    readTemp();
    bool alarm = !isnan(tempC) && (tempC < tempLo || tempC > tempHi);
    if (alarm && !tempAlarm) { Serial.print(F("TEMP ALARM ")); Serial.println(tempC, 1); }
    tempAlarm = alarm;
    setOutputs();
    if (tempAlarm) beep(60, 5, 60);
  }
#endif
#if USE_DS18B20 || USE_TSL2591 || USE_PH
  if (everyMin > 0 && millis() - lastReportMs > everyMin * 60000UL) {
    lastReportMs = millis();
    printSensors();
  }
#endif
}

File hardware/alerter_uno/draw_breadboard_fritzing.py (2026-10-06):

"""
draw_breadboard_fritzing.py -- Fritzing / circuito.io style breadboard picture (stage 1 + NEW stage 2)
======================================================================================================
Builds breadboard_stage2.svg from real Fritzing part art (CC-BY-SA, fritzing-parts repo, branch
`develop`), placing every leg on a real breadboard hole by reading the connector positions out of
the part SVGs, then renders breadboard_stage2.png with headless Chrome.

Run (base env):
    ~/anaconda3/python.exe hardware/alerter_uno/draw_breadboard_fritzing.py

Circuit (pins match alerter_uno.ino):
  stage 1: D6 -330-> green LED, D5 -220-> blue LED, D9 -220-> white LED,
           D2 -330-> PN2222A #1 base, emitter GND, collector -> buzzer(-), buzzer(+) -> 5V
  stage 2: D10 -330-> PN2222A #2 base, emitter GND, collector -> relay COIL 1,
           relay COIL 2 -> 5V, 1N4007 anode on collector / cathode (stripe) on 5V,
           relay COM -> 5V, relay NO -220-> red LED ("pump") -> GND, NC empty.
Units inside the SVG: 1 unit = 1/90 inch (breadboard hole pitch = 9 units).
"""
import math
import os
import re
import subprocess
import sys
import urllib.request

from lxml import etree

HERE = os.path.dirname(os.path.abspath(__file__))
PARTS = os.path.join(HERE, "fritzing_parts")
OUT_SVG = os.path.join(HERE, "breadboard_stage2.svg")
OUT_PNG = os.path.join(HERE, "breadboard_stage2.png")
RAW = "https://raw.githubusercontent.com/fritzing/fritzing-parts/develop/svg/core/breadboard/"
FILES = {
    "bb": "Half_breadboard56a.svg",
    "uno": "arduino_Uno_Rev3_breadboard.svg",
    "led": "LED-5mm-red-leg.svg",
    "res": "resistor_220.svg",
    "npn": "transistor_npn.svg",
    "diode": "diode.svg",
    "buzzer": "sparkfun-electromechanical_buzzer-12mm-ns_breadboard.svg",
    "relay": "sparkfun-electromechanical_relay-jzc_breadboard.svg",
}
SVGNS = "http://www.w3.org/2000/svg"
UPI = 90.0                      # global units per inch
PNG_W = 1600
CHROME = r"C:/Program Files/Google/Chrome/Application/chrome.exe"
NUM = r"[-+]?(?:\d*\.\d+|\d+\.?)(?:[eE][-+]?\d+)?"


# ---------------------------------------------------------------- affine helpers
def mul(A, B):      # A o B  (apply B first)
    a, b, c, d, e, f = A
    g, h, i, j, k, l = B
    return (a * g + c * h, b * g + d * h, a * i + c * j, b * i + d * j, a * k + c * l + e, b * k + d * l + f)


def T(x, y):
    return (1, 0, 0, 1, x, y)


def S(sx, sy=None):
    return (sx, 0, 0, sx if sy is None else sy, 0, 0)


def R(deg):
    r = math.radians(deg)
    return (math.cos(r), math.sin(r), -math.sin(r), math.cos(r), 0, 0)


def ap(M, p):
    a, b, c, d, e, f = M
    return (a * p[0] + c * p[1] + e, b * p[0] + d * p[1] + f)


def parse_tf(s):
    M = (1, 0, 0, 1, 0, 0)
    for name, args in re.findall(r"(\w+)\s*\(([^)]*)\)", s or ""):
        v = [float(x) for x in re.findall(NUM, args)]
        if name == "translate":
            m = T(v[0], v[1] if len(v) > 1 else 0)
        elif name == "scale":
            m = S(v[0], v[1] if len(v) > 1 else v[0])
        elif name == "rotate":
            m = R(v[0])
            if len(v) == 3:
                m = mul(T(v[1], v[2]), mul(m, T(-v[1], -v[2])))
        elif name == "matrix":
            m = tuple(v)
        else:
            continue
        M = mul(M, m)
    return M


def fmt(M):
    return "matrix(%s)" % ",".join("%.5f" % v for v in M)


# ---------------------------------------------------------------- part loading
def fetch(fname):
    path = os.path.join(PARTS, fname)
    if not os.path.exists(path):
        os.makedirs(PARTS, exist_ok=True)
        urllib.request.urlretrieve(RAW + urllib.request.quote(fname), path)
    return path
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

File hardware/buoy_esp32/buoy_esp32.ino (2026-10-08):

/*
  buoy_esp32.ino -- autonomous water-quality buoy that runs the Narragansett bloom forecast ON THE CHIP
  ===================================================================================================
  Model: the fork's release model v2 (300 boosted trees, 23 features, bloom_model.h), forecast
         P(daily-mean chl > 10 ug/L within 7 days); ALERT if p >= BLOOM_THRESHOLD (0.45).
  Features: features.h, built from a rolling daily history exactly as the fork's training code
         (lags/rolling means over daily ROWS, min_periods max(2, w/3), chl_trend, chl_anomaly, month).

  Boot: SELF-TEST (selftest.h): model vs Python on 8 real rows, feature code vs the fork's columns on
        29 real days, PSS-78 reference values. Then "READY".

  DEMO / REPLAY mode (default: no sensors enabled). Serial Monitor at 115200, line ending "Newline":
      day <yyyy-mm-dd> <chl> <temp> <sal> <do> [clim]   one DAILY MEAN row (nan = missing);
                    optional 6th value = that day's chl_climatology (the replay tool sends the fork's)
      vec <23 numbers>   score a raw feature vector (BLOOM_FEATURES order, nan allowed)
      status   reset (clears the daily history)   selftest   hist (print the stored days)
      site <name>   name used in bulletins (e.g. Newport-Harbor), kept in NVS
      clim <month> <value>   per-site chl climatology for that month, kept in NVS (nan clears it)
      clim     show the table              climclear   erase it
      help
    Each scored day prints   F <date> chl=.. chl_lag1=.. ... month=..
                             P <date> p=0.123456 ALERT|idle n=<days in history>
    and, when something changes, a harbor bulletin   MSG <title> | <text>
      Bloom WARNING (alert turns on), All clear (turns off), Bloom detected (chl crosses 10),
      Buoy check needed (a sensor day was dropped). Demo days print them; sensor days also push them.

  SENSOR mode (set any USE_ flag below to 1; needs the libraries named next to it):
      samples every 15 min, keeps daily means, closes a day at local midnight; a day with fewer than
      MIN_READINGS (48) chl readings is dropped, like training; the last 30 days and all calibration
      live in NVS (Preferences), so a reboot keeps them.
      read     one sample line, not stored      date <yyyy-mm-dd> <hh:mm>   set the clock (no Wi-Fi)
      blank    fluorometer: plain seawater = zero chl      chlk <k>   ug/L per count (sonde-equivalent)
      gain l|m|h|x   TSL2591 gain (saved; redo blank/chlk after changing it)
      cal686 / cal918   pH probe in pH 6.86 / 9.18 buffer        cal   calclear
  Wi-Fi alerts (USE_WIFI 1): wifi <ssid>   wifipass <password>   ntfy <topic>   ntfytest
      Stored in NVS, never in this file. Every bulletin from a sensor day posts to ntfy.sh/<topic>.

  Outputs: onboard LED (GPIO 2) and relay (GPIO 26) ON while the latest forecast is ALERT.
  The tank loop rules (X, C_ok, MAX_ON) are NOT in this version: see controlHook() below.
  Wiring and a walkthrough: hardware/buoy_esp32/README.md.
*/
#include <Arduino.h>
#include <Preferences.h>
#include <time.h>
#include <sys/time.h>

// declared before any function: the Arduino builder puts its auto-prototypes here
enum Notify { N_SILENT = 0, N_SERIAL = 1, N_PUSH = 2 };   // bulletins: restore / demo day / live sensor day

#define ST_PRINTF(...) Serial.printf(__VA_ARGS__)
#include "selftest.h"            // pulls in bloom_model.h, features.h, pss78.h, test_vectors.h

// ---- sensors: set to 1 once the part is wired (Arduino IDE -> Library Manager for the library)
#ifndef USE_DS18B20
#define USE_DS18B20 0   // water temperature, GPIO 4     needs OneWire + DallasTemperature
#endif
#ifndef USE_TSL2591
#define USE_TSL2591 0   // chlorophyll fluorometer, I2C  needs Adafruit TSL2591 Library + Adafruit Unified Sensor
#endif
#ifndef USE_EZO_EC
#define USE_EZO_EC 0    // Atlas EZO-EC conductivity, I2C 0x64 -> salinity (PSS-78). Wire only, no library
#endif
#ifndef USE_PH
#define USE_PH 0        // analog pH module on GPIO 34 (logged only; pH is not a model feature)
#endif
#ifndef USE_WIFI
#define USE_WIFI 0      // ntfy.sh push alerts + NTP clock. Core libraries only
#endif
#define SENSOR_MODE (USE_DS18B20 || USE_TSL2591 || USE_EZO_EC || USE_PH)

#if USE_DS18B20
#include <OneWire.h>
#include <DallasTemperature.h>
#endif
#if USE_TSL2591 || USE_EZO_EC
#include <Wire.h>
#endif
#if USE_TSL2591
#include <Adafruit_Sensor.h>
#include <Adafruit_TSL2591.h>
#endif
#if USE_WIFI
#include <WiFi.h>
#include <WiFiClientSecure.h>
#include <HTTPClient.h>
#endif

// ---- pins (ESP32 Dev Module)
const int PIN_LED = 2;          // onboard blue LED
const int PIN_RELAY = 26;
const int PIN_TEMP = 4;         // DS18B20 data, 4.7 kOhm pull-up to 3.3 V
const int PIN_FLUOR_LED = 25;   // fluorometer's blue excitation LED (through a transistor)
const int PIN_PH = 34;          // ADC1 (ADC2 pins stop working while Wi-Fi is on)
const int PIN_SDA = 21, PIN_SCL = 22;
const uint8_t EZO_ADDR = 0x64;
const bool RELAY_ACTIVE_LOW = false;  // true for most opto-isolated relay modules
const unsigned long SAMPLE_MS = 15UL * 60UL * 1000UL;
const char *BUOY_TZ = "EST5EDT,M3.2.0,M11.1.0";   // days close at local midnight (Narragansett / LIS)

// ---- state
Preferences prefs;               // NVS namespace "buoy"
History hist;
float climTable[13];             // [1..12] chl climatology per month, NAN = unknown
bool alertOn = false, relayOn = false;
float lastP = NAN;
int32_t lastDate = 0;
int selftestFails = -1;
const float BLOOM_CHL = 10.0f;   // ug/L, the training label's bloom level
String siteName = "buoy";        // used in bulletins (`site`)

struct Cal { uint32_t magic; float blank, chlK, v686, v918; char gain; };
const uint32_t CAL_MAGIC = 0xB0A70001;
Cal cal = {CAL_MAGIC, NAN, NAN, NAN, NAN, 'm'};

// daily accumulator (sensor mode): sums of the 15-min readings of the current local day
struct Acc { int32_t date; double sChl, sTemp, sSal, sPh; uint16_t nChl, nTemp, nSal, nPh; };
Acc acc;
struct Sample { float temp, cond, sal, ph, phV, fl, chl; };   // one 15-min reading (NAN = sensor off)

#if USE_DS18B20
OneWire oneWire(PIN_TEMP);
DallasTemperature ds(&oneWire);
#endif
#if USE_TSL2591
Adafruit_TSL2591 tsl = Adafruit_TSL2591(2591);
bool tslOk = false;
#endif
#if USE_WIFI
String wifiSsid, wifiPass, ntfyTopic;
#endif
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

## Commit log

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2026-05-26 Enhance HAB prediction system with updated methods and features
    - Updated paper outline with new authorship and expanded abstract detailing contributions and results.
    - Improved aeration intervention framework with fixed physical normalization for scoring.
    - Revised dashboard documentation to reflect changes in authorship and intervention criteria.
    - Added conditional satellite evaluation script to assess the impact of satellite data on model performance.
    - Enhanced model training scripts with improved feature engineering and evaluation metrics.
    - Updated seasonal intervention analysis and visualization for better clarity on intervention windows.
    - Refined data handling in sequence building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
2026-06-01 Add new models for bloom prediction: station thresholds, scale_pos_weight tuning, and two-stage classifier
    - Implemented `station_thresholds.py` to fit per-station decision thresholds based on historical bloom data, improving prediction accuracy for varying bloom rates across stations.
    - Created `tune_scale_pos_weight.py` to optimize the `scale_pos_weight` parameter for XGBoost, maximizing precision on the validation set while maintaining test set integrity.
    - Developed `two_stage_classifier.py` to enhance bloom detection using a two-stage approach: a recall-optimized logistic regression model followed by a precision-optimized model to filter candidates.
    - Added comprehensive logging and rep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
2026-06-02 Restore 3-way temporal split in daily_inference (train <=2019, val 2020-2022)
    Change the validation window from 2022-only back to the original 2020-2022,
    training on 1993-2019 instead of 1993-2022. Val period now covers 1,057
    station-days (was 382). A4 on 2022-07-19 still flags high risk (P=0.813) and
    Test AUC holds at 0.822. Update docstring, print headers, and comments to
    reflect the new split years.
2026-06-04 Add percent_saturation feature: precision 0.446->0.465
    Merge in percent_saturation from the raw depth_code=S ERDDAP extracts
    (data/raw/deep_wq_extra/deep_wq_S_*.csv): concatenate the per-year files,
    drop the units row, parse the UTC timestamps (which encode local midnight,
    so the UTC date is the local sample date), aggregate to one value per
    (date, station_name), and merge onto the feature matrix before it is built.
    Add percent_saturation to FEATURES_ALL in both daily_inference.py and
    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
2026-06-04 Add feature strategy search: test 6 alternative feature set approaches
    Tests CHL-only, Physical-only, Nutrient-focused, Spatial-only, PCA variants,
    and LASSO selection vs the 34-feature baseline. No strategy beats the baseline
    (Prec=0.465, F1=0.455). LASSO retains all 34 features confirming each is load-
    bearing at C=0.05.
2026-06-04 Add era_split_models.py: test 6 era-split/weighting strategies
    All 6 experiments confirm mixed-era baseline (1993-2019) is optimal.
    Post-TMDL-only and two-stage warm start hurt precision (FP increase).
    Adding post_tmdl as a feature collapses recall to 0.095 at threshold
    0.60 because the model correctly learns that post-2014 rows rarely bloom
    but over-suppresses predictions. Era-split strategies exhausted.
2026-06-05 narragansett_transfer_test.py: NBPTS nutrients do not improve baseline
    No NBPTS feature (PO4, NO3_2, ChlA, Secchi, Temperature) improves test
    F1 or precision at threshold 0.60. Best non-baseline ties at F1=0.493.
    Main blocker: NBPTS ends 2019, so val/test are fully median-imputed --
    no live signal transfer is possible. Training correlations are weak
    (max |r|=0.13). Narragansett Bay is not a useful regional nutrient proxy.
2026-06-12 checkpoint before stripping baked label from features csv
    [threshold_ci_table.csv]
2026-06-12 Add false positive audit and selective prediction scripts
    - Implemented `fp_audit.py` to categorize false positives based on chlorophyll readings and compute precision adjustments.
    - Introduced `selective_prediction.py` for a two-part analysis:
    - Part A checks window density of chlorophyll readings for false positives.
    - Part B evaluates selective prediction strategies based on station reliability and compares against baseline performance.
    - Both scripts include command-line argument parsing and output results to CSV and PNG files, respectively.
    [fp_audit_detail.csv, threshold_ci_table.csv]
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2026-07-12 Add buoy calibration failure diagnostics
2026-07-12 Audit flagged windows with uncalibrated buoy fluorescence
    Per-deployment calibration slopes swing >10x from biofouling and sensor
    swaps, so absolute ug/L is unrecoverable. The rank signal survives
    (Spearman ~0.5), so this asks a relative question instead: among CT DEEP
    negative windows, do model-flagged windows show higher buoy fluorescence
    than unflagged ones? Fouling drift is neutralized by z-scoring within year.
2026-07-12 Test spring-neap candidate feature in ablation study
    Adds spring_neap (from build_astro_features) as an additive candidate and
    evaluates it with a paired bootstrap AUC delta, so the correlation between
    the base and augmented models is preserved rather than compared as two
    independent CIs. Reports it as tested regardless of outcome.
2026-07-12 Add regularization sweep and ridge-trace figure
    Sweeps C across L1/L2 reporting validation AUC and the grouped chlorophyll
    coefficient share, plus a ridge-trace figure showing correlated chlorophyll
    features fanning out and stabilizing together under L2.
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2026-08-30 Docs: correct false deploy claim, reconcile precision conflict, mark stale notes, add Findings
    Truth-in-docs pass plus the consolidated findings section.
    Corrections to statements that were wrong:
    - README claimed src/deploy/ "still runs a superseded XGBoost model". False:
    daily_inference.py is v2, imports locked_pipeline, fits LR walk-forward in-process
    and loads no serialized model. The real stale artifact is dashboard.html (sidebar
    "Model: XGBoost / AUC 0.827"; parses aeration_score/do/temp/intervene columns the
    current script no longer emits). Both README lines corrected to say so.
    - PRECISION_CEILING_INVESTIGATION.md gave "~0.26" precision at t=0.60 with no horizon,
    conflicti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
2026-09-19 Desk day 2026-09-18/19: UConn talk, forms unblock, Phase 11 analysis frozen before the data
    - src/lab/: row-contract validator, synthetic season generator with planted truth,
    and the full LAB_PROTOCOL s8 analysis (H11a with the "consistent, underpowered"
    reading, H11b recovery and mass balance, H11c with D90 only when bracketed,
    counter agreement). Verified on four planted-truth scenarios and six corrupted rows.
    - notes/TALK_UCONN.md: 15-beat script and prepared answers for O'Donnell's group.
    - notes/ISEF_RESEARCH_PLAN.md: corrected the false "no hazardous materials" claim;
    real risk assessment, bench procedures, bench analysis, and a filled bibliography.
    - notes/COMPETITION_CHECKLIS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
    [lab_data_template.csv]
2026-09-23 LIS label rebuilt on the lab scale: the 2014 cliff was the CTD fluorometer
    CT DEEP confirmed (2026-09-22/23) that its lab and methods are unchanged for
    30+ years, that the CTD switched from SeaBird to YSI EXO2 around 2009/2010, that
    Corrected_Chlorophyll is corrected against the lab, and advised using lab data.
    The locked label came from the raw fluorometer, which read 2-3x the lab in
    1994-1999 and 2009-2013 and ~1x from 2016 on.
    - sensor_vs_lab_chl.py: per-year sensor/lab and corrected/lab ratios
    - LABEL_REBUILD_PREREG.md: series S0-S3 and gates written before any run;
    Amendment A1 adds S4 (lab only) after DEEP's advice, before it ran
    - label_rebuild.py: rebuilds Chlorophyll and every ch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
2026-09-24 Mitigation pivot: literature review, forecast-triggered treatment loop, Layer 1 replay
    The counselor rejected clay flocculation (it changes the environment and can't
    be retrieved in open water), so the hands-on half moves to low-impact,
    retrievable methods.
    - notes/HAB_MITIGATION_LITERATURE.md: 21 hand-checked entries (Part 1), 711
    auto-compiled from a 3,352-paper OpenAlex citation snowball (Part 2, full
    list in HAB_MITIGATION_SOURCES.csv), and 224 agent-read entries in five
    method families with a ranked shortlist (Part 3; notes/snowball/*.md).
    - notes/mitigation/: shared on/off control loop (predict -> treat X -> re-measure
    -> off) plus process docs for bubbles, seaweed, peroxide b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
    [HAB_MITIGATION_SOURCES.csv]
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2026-09-26 Mitigation evidence reviews, 256-paper scoreboard, full-text re-read
    - Evidence reviews for the five loop methods (20-27 sources each) and the
    execution plan (screens, two loop runs, timeline, shopping list).
    - Scoreboard data for 15 methods / 256 papers, rubric-scored by separate
    agents; build_scoreboard.py joins papers, scores, study types, calibration.
    - 197/256 papers read in full; merge_fulltext.py applies the corrections and
    the upgraded papers were re-scored.
    - 01_BUBBLES / EXECUTION_PLAN: bubble dose set from Sung & Gobler's full text
    (25 and 300 mL/min into 500 mL, air stone).
    Claude-Session: https://claud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
2026-09-26 Layer 2: simulate the five treatment loops in tanks; apply the design changes
    - src/sim/tank_model.py, loop_controller.py, method_mc.py: closed-loop bench
    simulation (arms A-D, n=3, 2,000 draws per method); parameters with source
    paper ids in method_params.csv, kept only if they reproduce their
    calibration paper. Controller matches Layer 1 run_loop exactly.
    - Results (LAYER2_SIM_RESULTS.md): seaweed 75% peak cut, shellfish needs
    2 tank volumes/day, bubbles mostly delay the bloom, peroxide and curcumin
    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
    [method_params.csv]
2026-09-26 Alerter on Arduino Uno: loop firmware, staged build guide, wiring pictures, materials list
    - hardware/alerter_uno/alerter_uno.ino: the ON/OFF loop rules (same as
    src/sim/loop_controller.py) on an Uno; LEDs, passive buzzer, relay on D10
    (PN2222A + 1N4007); optional DS18B20. Stages 1-2 built and tested.
    - README: 9-stage build plan with "done when" checks and a shopping list.
    - Wiring pictures: circuito.io snapshot, Fritzing-art breadboard drawing
    (stage 2 relay), relay breadboard sketch, schematic (with their scripts).
    - notes/mitigation/MATERIALS_LIST.md: materials per experiment.
    - SCIENTIFIC_METHOD.md: session entry.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
    [alerter_uno.ino, draw_breadboard_fritzing.py, draw_relay_breadboard.py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]
2026-09-27 Alerter laptop link: serial driver, hardware check, borrow lists
    - hardware/alerter_uno/alerter_link.py: sends day/p/chl to the Uno, checks every
    reply against src/sim/loop_controller.py, logs to CSV; --today restores the
    Uno's state after a USB reset (history replayed muted); --sim for no board.
    Real Uno: 3,287 Narragansett F7 days, 10 episodes, 0 mismatches.
    - alerter_uno.ino: `mute 0|1` command.
    - README: stage 7 usage and results; buzzer back on its transistor, with a
    warning about split power rails on full-size breadboards.
    - notes/mitigation/BORROW_LISTS.html: printable chem and robotics borrow lists.
    - SCIENTIFIC_METHOD.md: laptop-link result. .gitignore: local run logs.
    Co-A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
    [alerter_link.py, alerter_uno.ino]
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2026-09-28 Fluorometer dark box: 3D-printable cuvette holder (STL + generator)
    hardware/fluorometer_box/make_box.py builds fluorometer_box.stl and
    fluorometer_cap.stl (trimesh + manifold booleans) and a preview:
    - 13.2 mm well for a standard 12.5 mm cuvette, 5 mm floor;
    - 5 mm LED bore (-X) and a 6 mm sensor window at 90 deg (+Y), both at the
    15 mm beam height;
    - 5 mm pocket for the Adafruit TSL2591 STEMMA QT board (25.4 x 17.8) with a
    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
    [fluorometer_box.stl, fluorometer_cap.stl]
2026-09-29 Layer 2 sim: reactive arm C from a pilot bloom run; overshoot check
    Arm C now starts at 50% of the expected untreated peak (set by a simulated
    pilot bloom run); the old after-the-peak arm is kept as Cl for comparison.
    B beats reactive C in 98-100% of runs for every method; a reactive start at
    10-20% of peak still does worse than B. Optional floor rule (off by default):
    it never fired during treatment, since dips below normal come weeks after OFF
    (no nutrient recycling in the model).
    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
2026-09-29 Bench plan: make-or-break fixes, H4, percarbonate, materials explained
    - Arm C redefined as a reactive start (50% of expected peak); model-to-rule
    trigger handover; pilot bloom run; fluorometer sampling rules; Skeletonema
    as the lead diatom; per-method fixes (kelp cold holding, seaweed-only
    control, market-oyster backup, CO2 bubbling control, low-range peroxide
    kit, size-fractionation, curcumin correction curve)
    - H4: trim the bloom, don't push algae below normal (floor OFF rule)
    - Texas A&M pond-management sources; bubbles reframed as oxygen protection
    - Peroxide: calcium peroxide bag dropped; pumped liquid H2O2 in the loop,
    sodium percarbonate as the screen comparison
    - Materials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
2026-09-29 Declare 20 missing dependencies; add dependency check; fix row-shift label
    environment.yml gains polars, joblib, python-dotenv, ephem, cdsapi and the
    experiment libs (from worktree-climatology-fix da8e13f) plus the hardware
    and device-sim libs (pyserial, trimesh, manifold3d, schemdraw, lxml,
    magpylib). tests/check_dependencies.py skips .venv and .agents.
    warning_threshold_selection.py (unused duplicate of warning_operating_point)
    gets the branch's fix for its 21-row shift(-7) label (3e4893e).
    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
2026-09-29 28-day eval: alert-budget threshold (<= 8 alerts/month on validation)
    Second operating point fixed by capacity, not a test score: the lowest
    threshold whose 2020-22 validation alerts average <= 8 per month (the
    existing decision_value.py sampling budget). t = 0.47; test precision
    0.223 [0.125, 0.311], recall 0.615, lift 3.27 [2.43, 4.15].
    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
2026-09-29 Bench audit fixes: pulsed peroxide, floor/handover rules, reconciled plan
    - Peroxide modelled as pumped pulses with a direct-spike back-test; S3 now
    tests 3 x 0.8 mg/L pulses vs 1.6 mg/L.
    - Floor (2 days below 80% of warm-up, not arm D) and forecast-to-rule
    handover in loop_controller, alerter firmware and link; MAX_ON is a
    parameter; optional servo on D11; gain saved to EEPROM; configurable
    temperature window; stop logged for replay.
    - Layer 2 MC: C_ok from the pilot, Welch H1a interval, curcumin peak
    without the fluorometer artefact, recipe-scale nutrients; re-run.
    - Docs reconciled (24 tanks, shellfish X=3 d, H3, flask counts, dilutions,
    peristaltic pump); Form 3 limits, bleac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
    [method_params.csv]
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2026-10-03 Audit fixes: peroxide pulse mode in firmware, v2 trigger 0.45, timeline option 1, plan leftovers removed
    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
    [alerter_link.py, alerter_uno.ino, ph_offset_tune.ino]
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2026-10-07 Replace the clay-device research plan with the current aeration + peroxide plan (Form 1A structure)
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2026-10-11 ESP32 live dashboard; hardware bench notes (relay module, buzzer driver, ESP32 sensors + pH divider on the real board)
    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
2026-10-15 Printable submerged sensing head (converging and straight optics, lid, shroud); notes: dilution series, drift and milk test
    hardware/sensing_head/make_head.py generates the STLs: glass window in the underside, LED and
    TSL2591 bores tilted 25 deg so the beams cross ~10 mm below the glass (straight version for
    comparison), chip-down sensor pocket with plug notches, 12 mm HB650 long-pass filter recess,
    PG7 lid, shroud holding a fixed 12 mm water gap with M3 hold-down screws. Meshes checked:
    closed, single piece, on the bed. The old cuvette dark box is removed.
    Cardboard prototype results: dilutions halve the signal from 1/16 down; untouched zero drifts
    ~0.1 count/min; slightly milky water read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
